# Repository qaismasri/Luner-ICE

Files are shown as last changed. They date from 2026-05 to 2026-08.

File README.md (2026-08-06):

<div align="center">

# Lunar-ICE Rover

**A remotely operated lunar rover that drives a simulated lunar surface and identifies rocks
by their radio, infrared, ultrasonic and magnetic signatures.**

Imperial College London · ELEC40006 Electronics Design Project 1 (EEERover) · Group 15

Documentation
Contents
Sensors
Architecture
Team

</div>

## About the project

The goal was to design and build, from scratch, a remotely controlled rover capable of exploring a simulated lunar surface and surveying the rocks it finds there. The rover has to be driven around large obstacles by a remote operator, park itself next to a target rock, and work out two things about it: **how old it is**, and **what type of rock it is**.

Nothing about the rock is visible from the outside. Everything the rover reports has to be recovered from four faint signals the rock emits — a radio transmission carrying its age, infrared pulses, an ultrasonic tone, and a magnetic field. Each of those needed its own sensor, its own analogue signal chain to pull a usable signal out of the noise, and its own place on the chassis.

The project ran over one term as a six-person group design exercise, and had to satisfy a handful of hard constraints:

- **Under 750 g** all-up mass
- **£60 budget** for components
- **3.3 V logic throughout** — the microcontroller's inputs are not 5 V tolerant
- Driven entirely by a **remote operator**, with no line-of-sight assumptions beyond the same Wi-Fi network

<div align="center">
<table>
<tr>
<td width="50%" align="center" valign="top">
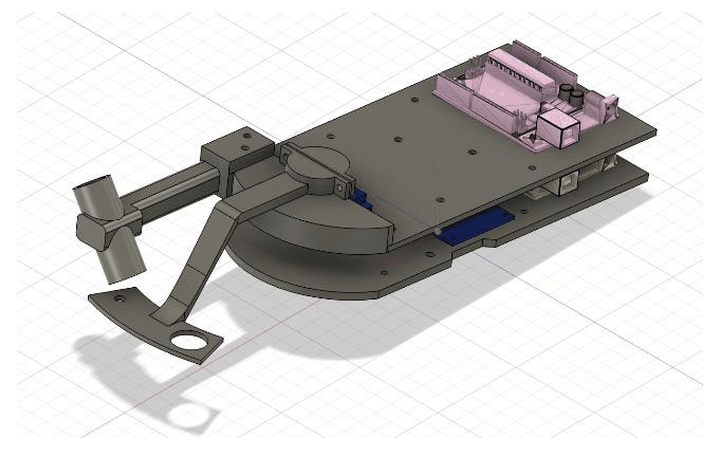
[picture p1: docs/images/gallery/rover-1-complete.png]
Complete rover chassis with both arms

<br><sub><b>Complete assembly</b> — both plates, radio arm and sensor arm</sub>
</td>
<td width="50%" align="center" valign="top">
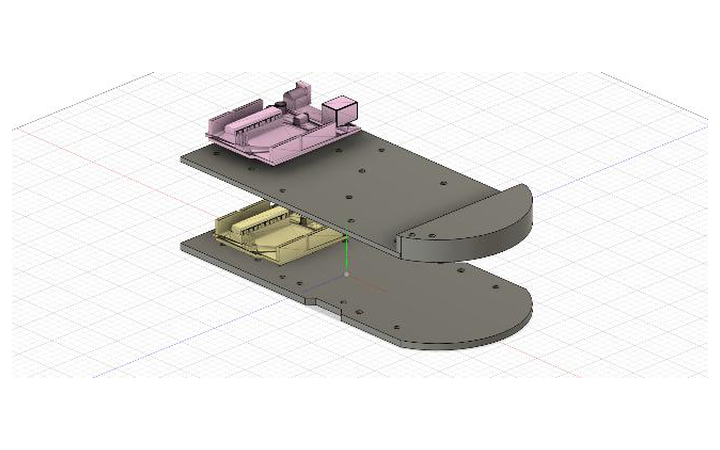
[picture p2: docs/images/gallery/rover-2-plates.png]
Base plate and sensor plate separated

<br><sub><b>Two-plate stack</b> — motors and power below, sensors above</sub>
</td>
</tr>
<tr>
<td width="50%" align="center" valign="top">
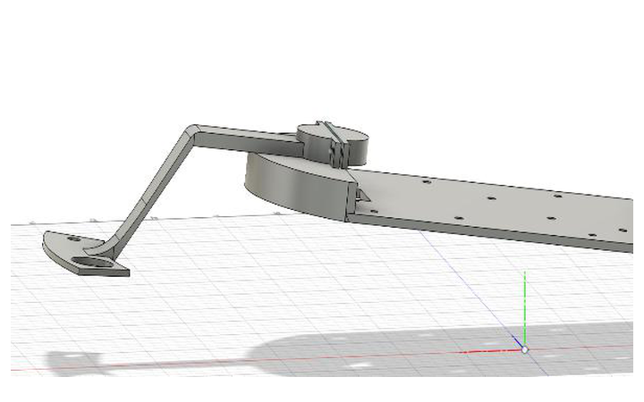
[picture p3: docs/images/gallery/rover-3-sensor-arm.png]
Sensor arm mounted on the chassis

<br><sub><b>Sensor arm</b> — sweeps three sensors across the rock</sub>
</td>
<td width="50%" align="center" valign="top">
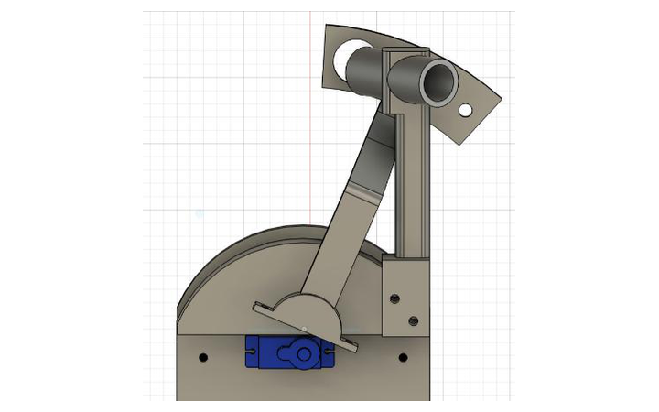
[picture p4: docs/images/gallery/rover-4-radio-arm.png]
Radio antenna arm mounted on the sensor plate

<br><sub><b>Radio arm</b> — fixed, angled down toward the rock</sub>
</td>
</tr>
</table>
</div>

> These are the Fusion 360 renders. Photographs of the built rover are the one thing this repository still lacks — see [the wanted list](docs/images/README.md#photographs-still-wanted).

<div align="right"><a href="#lunar-ice-rover">Back to top</a></div>

## Contents

| Section | What you will find |
|:---|:---|
| **[About the project](#about-the-project)** | Goals, constraints and what the rover has to do |
| **[Team](#team)** | Who built it, and who did what |
| **[The sensors](#the-sensors)** | The four sensing subsystems, one picture each |
| **[Identifying a rock](#identifying-a-rock)** | How four signals become a rock type and an age |
| **[System architecture](#system-architecture)** | The two-board split and how data flows |
| **[Documentation](#documentation)** | All twelve technical chapters |
| **[Repository layout](#repository-layout)** | Where everything lives |
| **[Build and run](#build-and-run)** | Getting it onto the hardware |

For the full technical write-up — calculations, simulations, measurements and PCB files — go to **[the documentation](docs/README.md)**.

<div align="right"><a href="#lunar-ice-rover">Back to top</a></div>

## Team

**Group 15** — six first-year students, with the work split by subsystem.

| Name | Main contributions |
|:---|:---|
| **Tibor Varga** | Radio circuit design and LTspice simulation |
| **Junhao Liu** | Chassis and sensor arm CAD, magnetic sensing |
| **Qais Masri** | Radio research, PCB design, movement and controller, finances |
| **Tunir Sarkar** | Infrared sensor and firmware |
| **Yangping Li** | Motor subsystem and drive integration |
| **Shivang Mehra** | Ultrasound and magnetic sensing, integration |

<div align="right"><a href="#lunar-ice-rover">Back to top</a></div>

## The sensors

Four independent subsystems. The **radio** reports the rock's age; the other three combine to give its type.

<table>
<tr>
<td width="50%" align="center" valign="top">
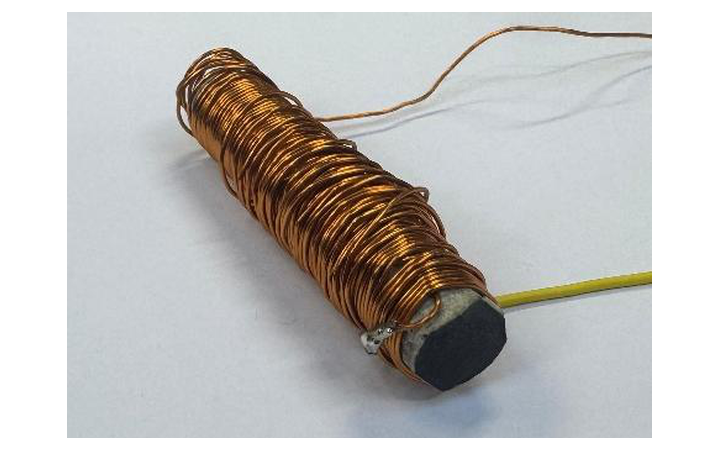
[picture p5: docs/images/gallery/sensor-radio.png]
Hand-wound ferrite coil antenna

<br><b>Radio</b> · rock age
<br><sub>120-turn ferrite coil tuned to 89&nbsp;kHz.<br>ASK carrier, UART at 600&nbsp;baud.</sub>
</td>
<td width="50%" align="center" valign="top">
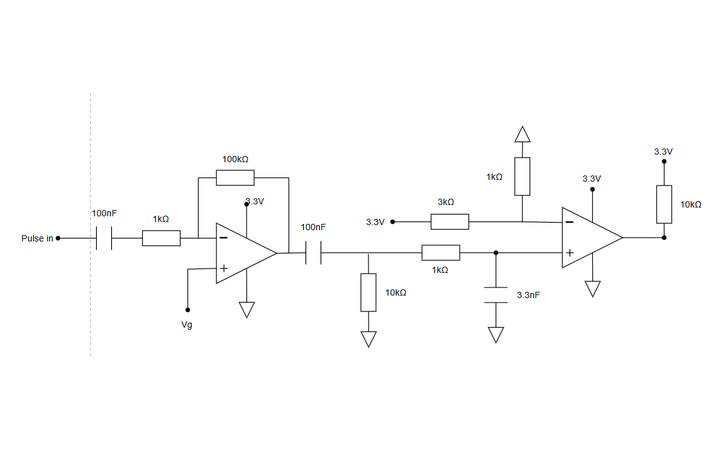
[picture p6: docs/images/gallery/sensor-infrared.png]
Infrared detection circuit

<br><b>Infrared</b> · rock type
<br><sub>SFH300 phototransistor, ×100 amplifier,<br>band-pass filter, LM393 comparator.</sub>
</td>
</tr>
<tr>
<td width="50%" align="center" valign="top">
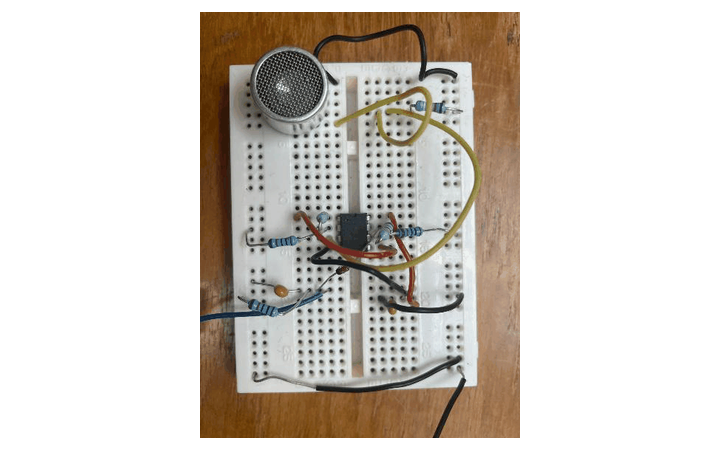
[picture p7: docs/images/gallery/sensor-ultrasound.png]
Ultrasonic receiver circuit on breadboard

<br><b>Ultrasound</b> · rock type
<br><sub>Prowave 400SR160 receiver, two ×34 stages,<br>deliberately clipped, envelope detected.</sub>
</td>
<td width="50%" align="center" valign="top">
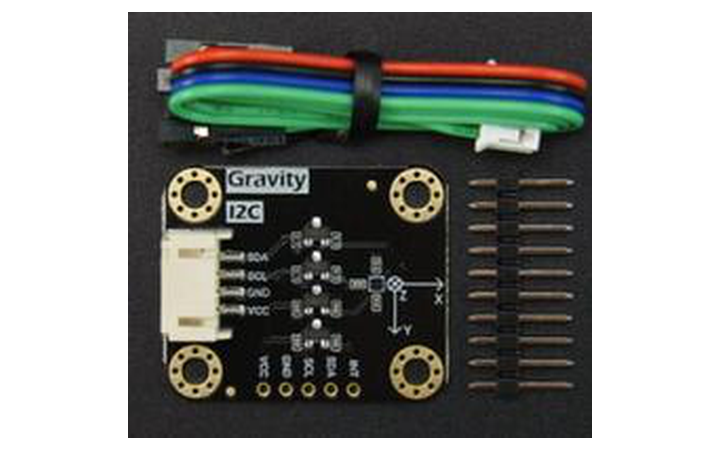
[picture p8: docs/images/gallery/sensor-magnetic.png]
DFRobot SEN0619 magnetometer module

<br><b>Magnetic</b> · rock type
<br><sub>SEN0619 (BMM350) TMR magnetometer,<br>0.1&nbsp;µT resolution over I²C.</sub>
</td>
</tr>
</table>

Click any sensor to read its full design write-up.

<div align="right"><a href="#lunar-ice-rover">Back to top</a></div>

## Identifying a rock

Each rock type maps to a unique combination of the three type-sensors:

| Rock type | Infrared | Ultrasound | Magnetic |
|:---|:---|:---|:---|
| **Basaltoid** | 547 Hz | Present | Down |
| **Gravion** | 312 Hz | Absent | Down |
| **Regolix** | 312 Hz | Present | Up |
| **Lunarite** | 547 Hz | Absent | Up |

Read as a truth table, any **two** of the three columns identify all four types. All three are measured anyway, so they cross-check one another and produce a **confidence score** — the figure that tells the operator when a reading is unreliable and should be rescanned.

The rover is driven and scanned entirely from a browser on the same Wi-Fi network, so the operator needs no special software.

<div align="center">
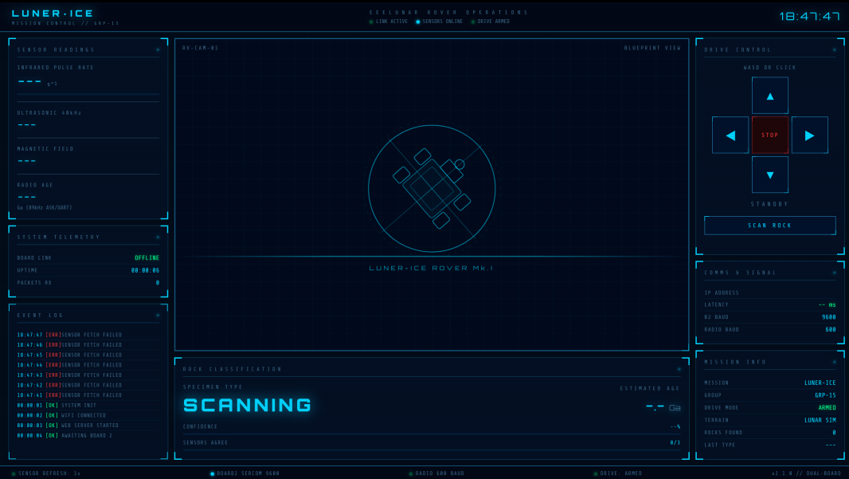
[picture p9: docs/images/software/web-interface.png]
Mission control web interface

</div>

<div align="right"><a href="#lunar-ice-rover">Back to top</a></div>

## System architecture

The rover runs on **two Adafruit Metro M0 Express boards**, split by responsibility. Board 2 does nothing but read sensors; Board 1 handles Wi-Fi, the motors and the classification. Keeping them separate means network activity can never disturb sensor timing.

```mermaid
flowchart LR
    subgraph Rock
        R["Target rock"]
    end

    subgraph B2["Board 2 — Sensing"]
        RAD["Radio<br/>89 kHz ASK"]
        IR["Infrared<br/>pulse counter"]
        US["Ultrasound<br/>40 kHz"]
        MAG["Magnetometer<br/>BMM350"]
    end

    subgraph B1["Board 1 — Control"]
        WEB["Wi-Fi web server"]
        CLS["Classification"]
        MOT["Motor driver"]
    end

    OP(["Operator<br/>browser + gamepad"])

    R --> RAD & IR & US & MAG
    RAD & IR & US & MAG --> PKT["Sensor packet @ 1 Hz"]
    PKT -->|"UART link"| B1
    WEB <-->|HTTP over Wi-Fi| OP
    CLS --> WEB
    MOT --> WHEELS["Drive motors"]
```

<div align="center">
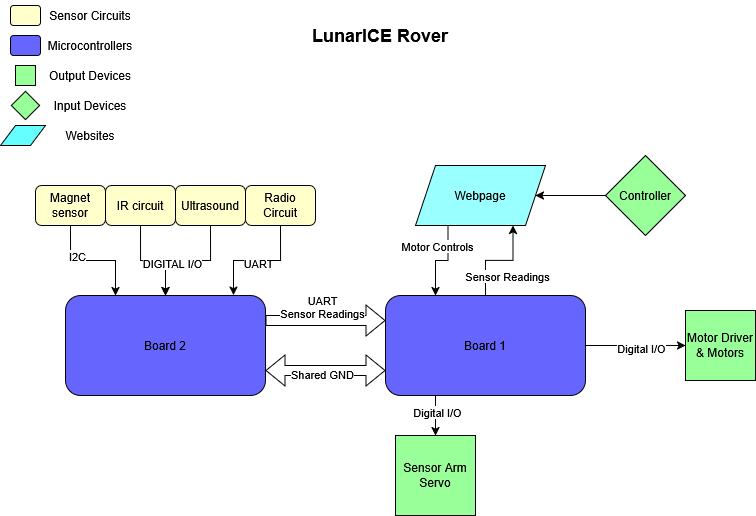
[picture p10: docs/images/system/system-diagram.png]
System diagram of the rover

</div>

<div align="right"><a href="#lunar-ice-rover">Back to top</a></div>

## Documentation

The complete write-up — design reasoning, calculations, LTspice simulations, oscilloscope captures, CAD renders and PCB layouts — lives in [`docs/`](docs/README.md).

| # | Chapter | What it covers |
|:--|:---|:---|
| 01 | [System overview](docs/01-system-overview.md) | Mission objectives, rock types, architecture, data flow |
| 02 | [Infrared sensing](docs/02-infrared.md) | Phototransistor front-end, band-pass filtering, comparator, pulse counting |
| 03 | [Radio sensing](docs/03-radio.md) | Ferrite antenna, tuned LC, amplifier, envelope detector, Schmitt trigger, UART decode |
| 04 | [Ultrasound sensing](docs/04-ultrasound.md) | 40 kHz transducer, two-stage gain, deliberate clipping, envelope detection |
| 05 | [Magnetic field sensing](docs/05-magnetic-field.md) | Hall-effect dead end, switch to a TMR magnetometer, thresholds |
| 06 | [Mechanical design](docs/06-mechanical-design.md) | Two-plate chassis, radio arm, servo-driven sensor sweep arm |
| 07 | [Movement and control](docs/07-movement-and-control.md) | Tank steering, keyboard control, gamepad mixing, latency fix |
| 08 | [PCB design](docs/08-pcb-design.md) | Two-board split, schematics, footprints, layout rules |
| 09 | [Web interface](docs/09-web-interface.md) | Mission control page, chunked serving, scan workflow |
| 10 | [Dual-board architecture](docs/10-dual-board-architecture.md) | Why two boards, the UART link, packet format, classification |
| 11 | [Cost and bill of materials](docs/11-cost-and-bom.md) | Component spend against budget |
| 12 | [References](docs/12-references.md) | Datasheets and sources |

New to the project? Start with [chapter 01](docs/01-system-overview.md).

<div align="right"><a href="#lunar-ice-rover">Back to top</a></div>

## Repository layout

```
Lunar-ICE/
├── docs/                      Technical documentation and all 71 figures
│
├── Full_Board_Code/           Flight firmware — the code that runs on the rover
│   ├── Board 1/               Wi-Fi, web server, motors, rock classification
│   └── Board 2/               All four sensors, streams readings to Board 1
│
├── Lonely_Board/              Single-board prototype (everything on one Metro M0)
│
├── sensing/                   Per-subsystem research, test firmware and PCBs
│   ├── Infrared/              IR pulse-detection test code
│   ├── radio/                 Coil calculations and radio test code
│   ├── ultrasonic/            Ultrasonic test code and design notes
│   ├── magnetic/              Magnetometer test code
│   └── PCBs/                  KiCad projects and manufacturing Gerbers
│
└── software/                  Web interface, servo tests, classification notes
    ├── Website/rover_website/ Board 1 firmware serving mission control
    └── Servo_test/            Sensor-arm servo sweep test
```

Every folder has its own README: [docs](docs/README.md) · [figures](docs/images/README.md) · [firmware](Full_Board_Code/README.md) · [prototype](Lonely_Board/README.md) · [sensing](sensing/README.md) · [software](software/README.md)

<div align="right"><a href="#lunar-ice-rover">Back to top</a></div>

## Build and run

You will need [PlatformIO](https://platformio.org/install) and two Adafruit Metro M0 Express boards, one with a WINC1500 Wi-Fi shield.

```bash
cd "Full_Board_Code/Board 1"     # Wi-Fi, web interface, motors, classification
pio run --target upload

cd "Full_Board_Code/Board 2"     # sensors
pio run --target upload
```

Board 1 prints its IP address over USB serial on boot — open it in a browser on the same network to drive the rover and trigger scans.

Wiring, Wi-Fi credentials and build notes are in **[Full_Board_Code/README.md](Full_Board_Code/README.md)**.

<div align="right"><a href="#lunar-ice-rover">Back to top</a></div>

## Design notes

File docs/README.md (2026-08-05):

[← Repo home](../README.md)

# Lunar-ICE — Technical Documentation

Complete design documentation for the Group 15 Lunar-ICE rover, covering every subsystem from first principles through simulation, bench measurement and final integration.

---

## Chapters

| # | Document | Covers |
|---|---|---|
| 01 | [System overview](01-system-overview.md) | Mission objectives, rock types, architecture, data flow |
| 02 | [Infrared sensing](02-infrared.md) | Phototransistor front-end, band-pass filtering, comparator, pulse counting |
| 03 | [Radio sensing](03-radio.md) | Ferrite antenna, tuned LC, amplifier, envelope detector, Schmitt trigger, UART decode |
| 04 | [Ultrasound sensing](04-ultrasound.md) | 40 kHz transducer, two-stage gain, deliberate clipping, envelope detection |
| 05 | [Magnetic field sensing](05-magnetic-field.md) | Hall-effect dead end, switch to a TMR magnetometer, thresholds |
| 06 | [Mechanical design](06-mechanical-design.md) | Two-plate chassis, radio arm, servo-driven sensor sweep arm |
| 07 | [Movement and control](07-movement-and-control.md) | Tank steering, keyboard control, gamepad mixing, latency fix |
| 08 | [PCB design](08-pcb-design.md) | Two-board split, schematics, footprints, layout rules |
| 09 | [Web interface](09-web-interface.md) | Mission control page, chunked serving, scan workflow |
| 10 | [Dual-board architecture](10-dual-board-architecture.md) | Why two boards, SERCOM UART link, packet format, classification |
| 11 | [Cost and bill of materials](11-cost-and-bom.md) | Component spend against budget |
| 12 | [References](12-references.md) | Datasheets and sources |

Every chapter carries previous / next / index links at the top and bottom, so you can read straight through or jump around.

---

## Reading order

If you are new to the project, read **[01 — System overview](01-system-overview.md)** first. It sets out the mission, the four rock types and how the sensor readings combine into a classification; everything else assumes that context.

The four sensing chapters (**02–05**) are independent of one another and can be read in any order. Chapters **06–10** cover integration and are best read after at least one sensing chapter.

---

## Looking for something specific?

| If you want to… | Go to |
|---|---|
| Understand the whole system in five minutes | [01 — System overview](01-system-overview.md) |
| See how a rock gets classified | [10 § Rock classification](10-dual-board-architecture.md#107-rock-classification) |
| Know why there are two microcontrollers | [10 § Why two boards](10-dual-board-architecture.md#102-why-two-boards) |
| Build or flash the firmware | [Full_Board_Code/README.md](../Full_Board_Code/README.md) |
| Reproduce a sensor circuit | [02](02-infrared.md) · [03](03-radio.md) · [04](04-ultrasound.md) · [05](05-magnetic-field.md) |
| Rebuild the radio front-end step by step | [sensing/radio/README.md](../sensing/radio/README.md) |
| Get the PCB manufacturing files | [08 § Manufacturing files](08-pcb-design.md#87-manufacturing-files) |
| Print the chassis | [06 — Mechanical design](06-mechanical-design.md) |
| See what the interface looks like | [09 — Web interface](09-web-interface.md) |
| Check what was spent | [11 — Cost and BOM](11-cost-and-bom.md) |
| Find a specific figure | [images/README.md](images/README.md) |
| Contribute photographs | [images/README.md § Photographs still wanted](images/README.md#photographs-still-wanted) |

---

## Code and hardware

The documentation explains the design; these folders hold the working files.

| Folder | Contents |
|---|---|
| [`Full_Board_Code/`](../Full_Board_Code/README.md) | Flight firmware for both boards |
| [`Lonely_Board/`](../Lonely_Board/README.md) | Single-board prototype |
| [`sensing/`](../sensing/README.md) | Per-subsystem test firmware, research notes, PCB projects |
| [`software/`](../software/README.md) | Web interface, gamepad driver, servo test |

---

## Figures

All 71 figures live under [`images/`](images/), grouped by subsystem. See **[images/README.md](images/README.md)** for the figure index — and for the list of photographs that would still improve this documentation, chiefly of the assembled rover.

---

## Source

This documentation is derived from the group's submitted project report, *ELEC40006 Project Report — Group 15*, expanded with repository-specific detail (build instructions, file locations, wiring) that the report did not need to carry.

Where the report and this documentation disagree on a number, the discrepancy is called out explicitly in place — see [11 § A note on the conflicting totals](11-cost-and-bom.md#112-a-note-on-the-conflicting-totals) for the one instance.

---

[← Repo home](../README.md)

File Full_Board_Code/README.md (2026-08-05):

[← Repo home](../README.md) · [Technical documentation](../docs/README.md)

# Flight Firmware — Dual-Board Setup

The code that actually runs on the Lunar-ICE rover. Two independent [PlatformIO](https://platformio.org/) projects, one per Adafruit Metro M0 Express board.

> **Full write-up:** [docs/10-dual-board-architecture.md](../docs/10-dual-board-architecture.md)

---

## The two boards

| | [`Board 1/`](Board%201/) | [`Board 2/`](Board%202/) |
|---|---|---|
| **Role** | Control | Sensing |
| **Responsibilities** | Wi-Fi, web interface, motors, rock classification | Radio, infrared, ultrasonic, magnetic |
| **Shield** | WINC1500 Wi-Fi | — |
| **Link** | Receives on pin 11 | Sends on pin 10 |
| **Env name** | `board1_main` | `board2_sensors` |

Board 2 sends one newline-terminated CSV packet per second:

```
AGE:3.82,IR:539,IRC:547,IRCO:93,US:1,MAG:DOWN
```

---

## Wiring between the boards

Two conductors — the link is one-way, because Board 2 only ever sends.

```
Board 2 pin 10 (TX)  ──────▶  Board 1 pin 11 (RX)
Board 2 GND          ───────  Board 1 GND
```

The link runs on **SERCOM1** at 9600 baud, mapped to those pins with `pinPeripheral()`. Pin 0 was unavailable on both boards — taken by the radio on Board 2, and physically dead on Board 1.

---

## Building and uploading

```bash
# Board 1
cd "Board 1"
pio run --target upload

# Board 2
cd "Board 2"
pio run --target upload
```

**Before flashing Board 1**, set your Wi-Fi credentials near the top of `Board 1/src/main.cpp`. On boot Board 1 prints its IP address over USB serial:

```bash
pio device monitor
```

Open that address in a browser on the same network to reach mission control.

---

## Build notes

**`lib_ignore = Adafruit TinyUSB Library` is required** in both `platformio.ini` files. Without it the build fails on a USB symbol conflict with the WiFi101 stack. Do not remove it.

**Board 1 resource use:** ~38% of 256 KB flash, ~18% of 32 KB RAM. The web page is stored as a string in flash and streamed to the browser in 500-byte chunks — sending it in one transfer crashes the WINC1500 driver.

---

## Related

| | |
|---|---|
| Single-board prototype | [`Lonely_Board/`](../Lonely_Board/) |
| Per-sensor test firmware | [`sensing/`](../sensing/) |
| Web interface source | [`software/Website/rover_website/`](../software/Website/rover_website/) |

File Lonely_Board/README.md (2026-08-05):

[← Repo home](../README.md) · [Technical documentation](../docs/README.md)

# Single-Board Prototype

A complete, working implementation of the entire rover on **one** Adafruit Metro M0 Express — sensors, Wi-Fi, web interface, motors and classification in a single sketch.

> This is **not** the firmware that runs on the finished rover. That is in [`Full_Board_Code/`](../Full_Board_Code/).

---

## Why it exists

The final rover uses two boards. That was a deliberate design choice rather than a necessity, and this project is the evidence: a single Metro M0 genuinely can run the whole system. The 48 MHz Cortex-M0+ has ample compute, the time-sensitive inputs are protected by hardware (infrared on an interrupt, radio in an interrupt-driven UART buffer, motors on hardware PWM), and the firmware fits comfortably.

The split to two boards was made for **timing isolation** — serving the web page over the WINC1500 blocks the processor in bursts, which would otherwise disturb the 50 µs infrared pulse measurements — plus parallel development and a cleaner separation of concerns.

The full argument is in [docs/10-dual-board-architecture.md § 10.2](../docs/10-dual-board-architecture.md#102-why-two-boards).

---

## Keeping it around

It stays in the repository for three reasons:

1. It documents the alternative that was considered and measured, rather than merely asserted.
2. It is a useful fallback if one board fails during a demonstration.
3. It is the simplest place to reproduce an end-to-end bug without the inter-board link in the way.

---

## Building

```bash
pio run --target upload
```

Set your Wi-Fi credentials near the top of `src/main.cpp` first. On boot the board prints its IP address over USB serial.

Uses the [DFRobot_BMM350](https://github.com/DFRobot/DFRobot_BMM350) library for the magnetometer, pulled automatically via `lib_deps`.

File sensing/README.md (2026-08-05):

[← Repo home](../README.md) · [Technical documentation](../docs/README.md)

# Sensing

Research, circuit design, test firmware and PCB files for all four sensing subsystems on the Lunar-ICE rover.

Each subsystem detects one property of a rock and reduces it to a signal the Metro M0 can read. The full write-up for each — design reasoning, calculations, simulations and measurements — is in [`docs/`](../docs/); this folder holds the working files.

---

## Subsystems

| Subsystem | Detects | Documentation | Test firmware | Status |
|---|---|---|---|---|
| **Radio** | Rock age, via 89 kHz ASK | [docs/03-radio.md](../docs/03-radio.md) | [`radio/radio_test_code/`](radio/radio_test_code/) | ✅ Working |
| **Infrared** | Rock type, via pulse rate | [docs/02-infrared.md](../docs/02-infrared.md) | [`Infrared/ir_test_code/`](Infrared/ir_test_code/) | ✅ Working |
| **Ultrasound** | Rock type, via 40 kHz tone | [docs/04-ultrasound.md](../docs/04-ultrasound.md) | [`ultrasonic/ultrasonic_test_code/`](ultrasonic/ultrasonic_test_code/) | ✅ Working |
| **Magnetic** | Rock type, via magnet polarity | [docs/05-magnetic-field.md](../docs/05-magnetic-field.md) | [`magnetic/Magnetic_test_code/`](magnetic/Magnetic_test_code/) | ✅ Working |

---

## Folder contents

```
sensing/
├── Infrared/
│   └── ir_test_code/                  Pulse counting via hardware interrupt
├── radio/
│   ├── COIL_CALCULATIONS.md           Ferrite coil inductance and resistance working
│   ├── step1_coil_antenna.png         The wound coil
│   └── radio_test_code/               UART decode of the demodulated bitstream
├── ultrasonic/
│   ├── Ultrasonic_sensor_notes.md     Transducer, gain planning and test log
│   └── ultrasonic_test_code/          Digital-level presence detection
├── magnetic/
│   └── Magnetic_test_code/            BMM350 read over I²C
├── radio_ultrasound_magnetic/         Combined three-sensor integration test
└── PCBs/                              KiCad projects and manufacturing Gerbers
```

Each folder containing a `platformio.ini` is a standalone [PlatformIO](https://platformio.org/) project:

```bash
cd sensing/Infrared/ir_test_code
pio run --target upload
```

The **flight firmware** that actually runs on the rover is not here — it is in [`Full_Board_Code/Board 2/`](../Full_Board_Code/Board%202/), which combines all four subsystems. The projects in this folder are the per-subsystem test rigs used during development, kept because they are the quickest way to bring one sensor up in isolation when debugging.

---

## How it fits together

```mermaid
flowchart LR
    A["🪨 Rock"] --> B["Radio<br/>89 kHz ASK"]
    A --> C["Infrared<br/>312 / 547 Hz"]
    A --> D["Ultrasound<br/>40 kHz"]
    A --> E["Magnetic<br/>up / down"]

    B --> F["Board 2<br/>Metro M0"]
    C --> F
    D --> F
    E --> F

    F -->|"CSV packet @ 1 Hz over UART"| G["Board 1"]
    G --> H["Rock classification"]
```

The radio yields the rock's **age**. The other three combine to give its **type** — see [Rock classification](../docs/10-dual-board-architecture.md#107-rock-classification).

---

## PCBs

Two boards were manufactured. See [docs/08-pcb-design.md](../docs/08-pcb-design.md) for schematics, layout rules and 3D renders.

| Board | KiCad project | Gerbers |
|---|---|---|
| Radio | [`PCBs/Radio PCB/`](PCBs/Radio%20PCB/) | [`PCBs/Radio final PCB/`](PCBs/Radio%20final%20PCB/) |
| IR + ultrasound | [`PCBs/IR + ultrasound/`](PCBs/IR%20+%20ultrasound/) | [`PCBs/Infrared final pcb/`](PCBs/Infrared%20final%20pcb/) |
| Demo | [`PCBs/Demo pcb/`](PCBs/Demo%20pcb/) | [`PCBs/Final files greber/`](PCBs/Final%20files%20greber/) |

Magnetic sensing needs no PCB — the SEN0619 module outputs digitally over I²C and wires straight to the Metro.

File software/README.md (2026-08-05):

[← Repo home](../README.md) · [Technical documentation](../docs/README.md)

# Software

The operator-facing side of the Lunar-ICE rover: the mission control web interface, the classification logic, and the servo test rig.

---

## Contents

| Item | What it is |
|---|---|
| [`Website/rover_website/`](Website/rover_website/) | Board 1 firmware serving the mission control page, plus the gamepad driver |
| [`eeerover_mission_control_demo.html`](eeerover_mission_control_demo.html) | Standalone copy of the page — open it in a browser to preview the UI without hardware |
| [`Servo_test/`](Servo_test/) | Sensor-arm servo sweep test |
| [`rock_classification.md`](rock_classification.md) | Reference implementation of the four-way rock lookup |
| [`arduino_capabilities.md`](arduino_capabilities.md) | Early one-board-versus-two design note, kept for the record |

---

## Mission control

The rover is driven and monitored entirely through a browser on the same Wi-Fi network. Board 1 serves the page and prints its IP address over USB serial on boot.

| Topic | Documentation |
|---|---|
| What the page shows, chunked serving, scan workflow | [docs/09-web-interface.md](../docs/09-web-interface.md) |
| Tank steering, gamepad mixing, the latency fix | [docs/07-movement-and-control.md](../docs/07-movement-and-control.md) |
| Classification and confidence scoring | [docs/10-dual-board-architecture.md § 10.7](../docs/10-dual-board-architecture.md#107-rock-classification) |

### Previewing the interface without hardware

```bash
# macOS / Linux
open software/eeerover_mission_control_demo.html

# Windows
start software\eeerover_mission_control_demo.html
```

Drive controls and live readings will not do anything without a rover to talk to, but the layout, styling and animations all render.

---

## Gamepad support

[`Website/rover_website/src/gamepad.js`](Website/rover_website/src/gamepad.js) uses the browser's built-in Gamepad API for analogue steering:

| Input | Index | Meaning |
|---|---|---|
| Right trigger | `buttons[7]` | Forward throttle |
| Left trigger | `buttons[6]` | Reverse throttle |
| Right stick X | `axes[2]` | Steering |

Throttle and steer are mixed into per-wheel speeds and sent as `GET /drive?left=L&right=R`. A ±0.15 dead zone suppresses stick drift, and requests are sent only when values change — the original implementation fired ~30 requests per second and built up a command backlog that made the rover keep turning after the stick was released. See [docs/07-movement-and-control.md § 7.5](../docs/07-movement-and-control.md#75-the-latency-problem-and-the-fix).

---

## Building

Both PlatformIO projects build and upload the same way:

```bash
cd software/Website/rover_website
pio run --target upload
```

Set your Wi-Fi credentials near the top of `src/main.cpp` before flashing.

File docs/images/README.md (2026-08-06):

[← Documentation index](../README.md) · [Repo home](../../README.md)

# Figure Index

All figures used in the [technical documentation](../README.md), grouped by subsystem. **71 figures**, extracted from the group's project report and re-encoded for the web (longest edge capped at 1400 px).

Naming convention: `<subsystem>-<what-it-shows>.png`. Simulation captures carry `ltspice`, oscilloscope captures carry `scope`.

---

## Contents

- [Existing figures](#existing-figures)
- [Photographs still wanted](#photographs-still-wanted) ← **contributions go here**

---

## Existing figures

### `system/` — 1 figure

| File | Shows |
|---|---|
| `system-diagram.png` | Block diagram of the whole rover: sensors, both boards, motors, webpage, controller |

### `infrared/` — 13 figures

| File | Shows |
|---|---|
| `ir-virtual-ground.png` | Virtual ground potential divider, ~1.5 V at `Vg` |
| `ir-phototransistor-model.png` | Current source + NPN model of the SFH300 |
| `ir-inverting-amplifier.png` | Inverting amplifier, gain 100 |
| `ir-high-pass-filter.png` | 159 Hz high-pass stage |
| `ir-high-pass-bode.png` | High-pass magnitude response |
| `ir-low-pass-filter.png` | 48 kHz low-pass stage |
| `ir-band-pass-bode.png` | Combined 159 Hz – 48 kHz response |
| `ir-scope-amplified-pulses.png` | Amplified pulses, Vpp 900 mV |
| `ir-scope-comparator-out.png` | LM393 digital output |
| `ir-scope-pulse-zoom.png` | Single pulse showing noisy edges |
| `ir-scope-noisy-edge.png` | Residual noise before the threshold was raised |
| `ir-scope-smoothed-edge.png` | Clean edge after low-pass + higher threshold |
| `ir-full-circuit.png` | Complete IR signal chain schematic |

### `radio/` — 25 figures

| File | Shows |
|---|---|
| `radio-ask-uart-frame.png` | ASK on-off keying and UART frame structure |
| `radio-ferrite-coil.png` | Hand-wound 120-turn ferrite coil antenna |
| `radio-tuned-lc-circuit.png` | Tuned LC, 517 µH with 6.6 nF |
| `radio-ltspice-sources.png` | LTspice carrier and modulation source definitions |
| `radio-ltspice-ask-signal.png` | Simulated ASK waveform |
| `radio-scope-raw-ask.png` | Measured ASK signal at the antenna |
| `radio-mcp6002-slew-vs-temp.png` | MCP6002 slew rate vs temperature (rejected part) |
| `radio-mcp6022-slew-vs-temp.png` | MCP6022 slew rate vs temperature (selected part) |
| `radio-amplifier-schematic.png` | Non-inverting amplifier, gain 101 |
| `radio-ltspice-amplified.png` | Simulated rail-clipped amplifier output |
| `radio-scope-amplified.png` | Measured amplified signal |
| `radio-scope-raw-vs-amplified.png` | Raw against amplified, showing negative-half clipping |
| `radio-envelope-schematic.png` | Diode + 10 nF + 10 kΩ envelope detector |
| `radio-ltspice-envelope.png` | Simulated envelope output |
| `radio-ltspice-envelope-vs-amp.png` | Envelope overlaid on the amplified signal |
| `radio-ltspice-envelope-ripple.png` | Zoomed ripple from per-cycle discharge |
| `radio-ltspice-envelope-rc-too-big.png` | R = 30 kΩ — capacitor fails to fully discharge |
| `radio-scope-envelope.png` | Measured envelope output |
| `radio-scope-envelope-vs-amp.png` | Measured 0.64 V diode drop between stages |
| `radio-comparator-schematic.png` | Non-inverting comparator with divider-set threshold |
| `radio-ltspice-comparator.png` | Simulated clean 0–3 V digital output |
| `radio-ltspice-envelope-vs-digital.png` | Envelope and digital output overlaid at the 1.6 V crossing |
| `radio-scope-digital-out.png` | Measured digital output, 3.44 V |
| `radio-scope-amplified-vs-digital.png` | ASK input against recovered binary output |
| `radio-breadboard-final.png` | Complete radio front-end on breadboard |

### `ultrasound/` — 8 figures

| File | Shows |
|---|---|
| `us-sensitivity-vs-load.png` | 400SR160 sensitivity vs load resistance |
| `us-lt1366-gain-phase.png` | LT1366 gain and phase vs frequency (rejected part) |
| `us-mcp6022-open-loop-gain.png` | MCP6022 open-loop gain and phase (selected part) |
| `us-ltspice-circuit.png` | Full simulated circuit — two gain stages + envelope detector |
| `us-ltspice-envelope-output.png` | Simulated output settling to ~2.3 V |
| `us-breadboard-final.png` | Final circuit on breadboard with transducer |
| `us-scope-signal-present.png` | Output with 40 kHz present, ~2.63 V |
| `us-scope-signal-absent.png` | Output with no signal, ~45.6 mV |

### `magnetic/` — 3 figures

| File | Shows |
|---|---|
| `mag-ah49e-hall-sensor.png` | AH49E linear Hall-effect sensor (first attempt) |
| `mag-sen0619-module.png` | DFRobot SEN0619 / BMM350 magnetometer module |
| `mag-z-reading-vs-distance.png` | Z-axis reading vs distance, with the ±170 µT thresholds marked |

### `mechanical/` — 10 figures

| File | Shows |
|---|---|
| `chassis-complete.png` | Complete chassis CAD render with both arms |
| `chassis-plates-exploded.png` | Base plate and sensor plate separated |
| `radio-arm-initial.png` | Initial glued radio antenna holder |
| `radio-arm-initial-too-high.png` | Test fit — antenna sitting too far from the rock |
| `radio-arm-redesigned.png` | Screwed redesign at the correct height |
| `radio-arm-mounted-side.png` | Radio arm mounted on the sensor plate |
| `sensor-arm-sweep-restriction.png` | The 23° rightward sweep restriction |
| `sensor-arm-labelled.png` | Sensor arm with IR, ultrasound and magnetometer positions labelled |
| `sensor-arm-on-chassis.png` | Sensors arranged along the sweep arc |
| `sensor-arm-arc-support.png` | Arced support platform under the arm |

### `pcb/` — 8 figures

| File | Shows |
|---|---|
| `pcb-radio-schematic.png` | Radio board KiCad schematic |
| `pcb-radio-layout.png` | Radio board layout with ground plane |
| `pcb-radio-3d-render.png` | Radio board 3D render |
| `pcb-ir-ultrasound-schematic.png` | IR + ultrasound KiCad schematic |
| `pcb-ir-ultrasound-layout.png` | IR + ultrasound board layout |
| `pcb-ir-ultrasound-3d-render.png` | IR + ultrasound board 3D render |
| `pcb-unused-channels-schematic.png` | Unused MCP6022 and LM393 channels tied off safely |
| `pcb-kicad-footprint-manager.png` | KiCad footprint manager during component selection |

### `software/` — 3 figures

| File | Shows |
|---|---|
| `web-interface.png` | Mission control page in the browser |
| `flowchart-board1.png` | Board 1 firmware flowchart |
| `flowchart-board2.png` | Board 2 firmware flowchart |

---

## Derived assets

These are generated from the figures above rather than taken from the report. They exist to give the root README a consistent look; nothing in the documentation chapters depends on them.

### `gallery/` — 8 images

Each source figure is fitted onto a common 720 × 450 canvas with **transparent** padding, so the cells of the two galleries in the root README line up regardless of the source aspect ratio. Transparency means they adapt to the reader's light or dark theme.

**Rover gallery** — the four views at the top of the README:

| File | Built from |
|---|---|
| `rover-1-complete.png` | `mechanical/chassis-complete.png` |
| `rover-2-plates.png` | `mechanical/chassis-plates-exploded.png` |
| `rover-3-sensor-arm.png` | `mechanical/sensor-arm-on-chassis.png` |
| `rover-4-radio-arm.png` | `mechanical/radio-arm-mounted-side.png` |

**Sensor gallery** — one picture per subsystem:

| File | Built from |
|---|---|
| `sensor-radio.png` | `radio/radio-ferrite-coil.png` |
| `sensor-infrared.png` | `infrared/ir-full-circuit.png` |
| `sensor-ultrasound.png` | `ultrasound/us-breadboard-final.png` |
| `sensor-magnetic.png` | `magnetic/mag-sen0619-module.png` |

**If you replace a source figure**, regenerate the matching gallery image so the two stay in step. Every rover-gallery image is currently a CAD render — swapping in photographs of the built rover is the single biggest improvement available to this repository.

### `nav/` — 6 images

Button images for the root README. GitHub strips CSS from Markdown, so plain links cannot be restyled; rendering navigation as images is the only way to make it read as buttons rather than blue text. They are generated locally rather than pulled from a badge service, so the README has no external dependencies and renders offline.

Section jumps: `btn-documentation.png` (accent) · `btn-contents.png` · `btn-sensors.png` · `btn-architecture.png` · `btn-team.png`

Back to top: `btn-top.png` — the small muted pill repeated at the end of each README section.

---

## Photographs still wanted

Everything above documents the **design**. What the documentation lacks almost entirely is evidence of the **built rover** — there is not a single photograph of the finished machine anywhere in this repository.

That is the largest remaining gap. Anyone assessing this project will want to see that the design became a working object.

The slots below are reserved. Drop a file at the given path and the documentation will pick it up — each one is already referenced from the relevant page, so no editing is needed beyond adding the image.

### Priority 1 — the finished rover

| Path | What to shoot |
|---|---|
| `mechanical/rover-assembled.jpg` | **Most important.** Three-quarter view of the complete rover: both plates, wheels, both arms, wiring. Plain background, even lighting. Destined for the top of the root README. |
| `mechanical/rover-side-profile.jpg` | Side-on, showing the 35 mm plate separation and the sensor arm's ground clearance. |
| `mechanical/rover-scanning-rock.jpg` | Parked at a rock mid-scan with the arm swept over it. Shows the working geometry better than any render. |
| `mechanical/rover-top-down.jpg` | Directly overhead, showing the sensor plate layout — PCBs, Board 2, arm pivot. |
| `infrared/ir-breadboard-final.jpg` | The infrared circuit built on breadboard. **This is the one sensor gallery cell on the front page still showing a schematic rather than real hardware** — radio, ultrasound and magnetic are all photographs. Shoot this and regenerate `gallery/sensor-infrared.png` from it. |

### Priority 2 — subassemblies

| Path | What to shoot |
|---|---|
| `mechanical/sensor-arm-built.jpg` | Printed arm with IR, ultrasonic and magnetometer sensors fitted. |
| `mechanical/chassis-underside.jpg` | Underside of the base plate: motor mounting and notches. |
| `pcb/pcb-radio-populated.jpg` | Manufactured radio board, soldered. |
| `pcb/pcb-ir-ultrasound-populated.jpg` | Manufactured IR + ultrasound board, soldered. |
| `pcb/pcbs-mounted-on-chassis.jpg` | Both boards screwed to the sensor plate and wired in. |
| `radio/radio-antenna-mounted.jpg` | The ferrite coil in its arm on the rover, showing the downward angle. |

### Priority 3 — evidence and context

| Path | What to shoot |
|---|---|
| `software/web-interface-classified.png` | Screenshot immediately after a successful scan, showing a rock type, age and confidence figure. The current screenshot shows the page mid-scan. |
| `software/web-interface-mobile.png` | The page on a phone, demonstrating the responsive layout. |
| `system/rover-in-arena.jpg` | The rover on the test surface among the rocks — gives scale and context. |
| `system/team-photo.jpg` | The group with the finished rover. |
| `mechanical/print-in-progress.jpg` | A plate being 3D printed — supports the material discussion in [06](../06-mechanical-design.md#material-choice). |

### If you shoot new photographs

- **JPEG for photographs, PNG for screenshots and diagrams.** JPEG artefacts ruin text and line art; PNG bloats photographs.
- **Cap the longest edge at 1600 px.** Everything already here is capped at 1400 px, and the whole set totals ~5 MB.
- **Keep the filename exactly as listed above** so the existing references resolve.
- Plain, uncluttered background; diffuse light; avoid direct flash on the PCBs.

---

[← Documentation index](../README.md) · [Repo home](../../README.md)

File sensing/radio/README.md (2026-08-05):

[← sensing/](../README.md) · [Repo home](../../README.md) · [Technical documentation](../../docs/README.md)

# Radio Subsystem — Age Detection

**Signal:** 89 kHz carrier, amplitude-shift keyed, UART encoded at 600 baud
**Output:** rock age as an ASCII string — `#123` means 1.23 billion years

> **Full write-up:** [docs/03-radio.md](../../docs/03-radio.md) — design reasoning, LTspice simulations, oscilloscope captures and measured results for every stage.
> This page is the build guide: what to make, in what order, and what to check before moving on.

---

## Signal processing chain

```mermaid
flowchart TD
    A["🪨 Rock transmits 89 kHz ASK signal"] --> B
    B["1. Coil antenna<br/>Ferrite-cored inductor<br/>Picks up 89 kHz radio waves"] --> C
    C["2. Tuned LC circuit<br/>Antenna coil + capacitor<br/>Resonates at 89 kHz, filters noise"] --> D
    D["3. Amplifier<br/>Op-amp, high slew rate required<br/>Boosts signal to usable voltage"] --> E
    E["4. Envelope detector<br/>Diode + capacitor rectifier<br/>Strips carrier, keeps data shape"] --> F
    F["5. Comparator<br/>Compares against threshold voltage<br/>Outputs clean binary"] --> G
    G["6. Metro M0 UART decode<br/>Pin 0, 600 baud"] --> H
    H(["✅ Age value extracted<br/>#123 → 1.23 billion years"])
```

---

## Build order

Each step should be verified on the oscilloscope before the next is added. Debugging a five-stage analogue chain built all at once is far harder than building it one stage at a time.

### Step 1 — Coil antenna

Wind copper wire around a ferrite core to form an inductor. Ferrite was chosen over a plain air core because it significantly increases inductance for the same number of turns and physical size, improving sensitivity to weak signals. Measure the finished coil's inductance with the lab LCR bridge — **use the measured value, not the calculated one, to size the tuning capacitor.**

| Parameter | Value |
|---|---|
| Core | Ferrite, 1 cm diameter × 5.5 cm |
| Turns | 120 |
| Wire | 0.40 mm enamelled copper |
| Measured inductance | 517 µH |
| Measured resistance | 0.488 Ω |

Full calculations: [COIL_CALCULATIONS.md](COIL_CALCULATIONS.md)

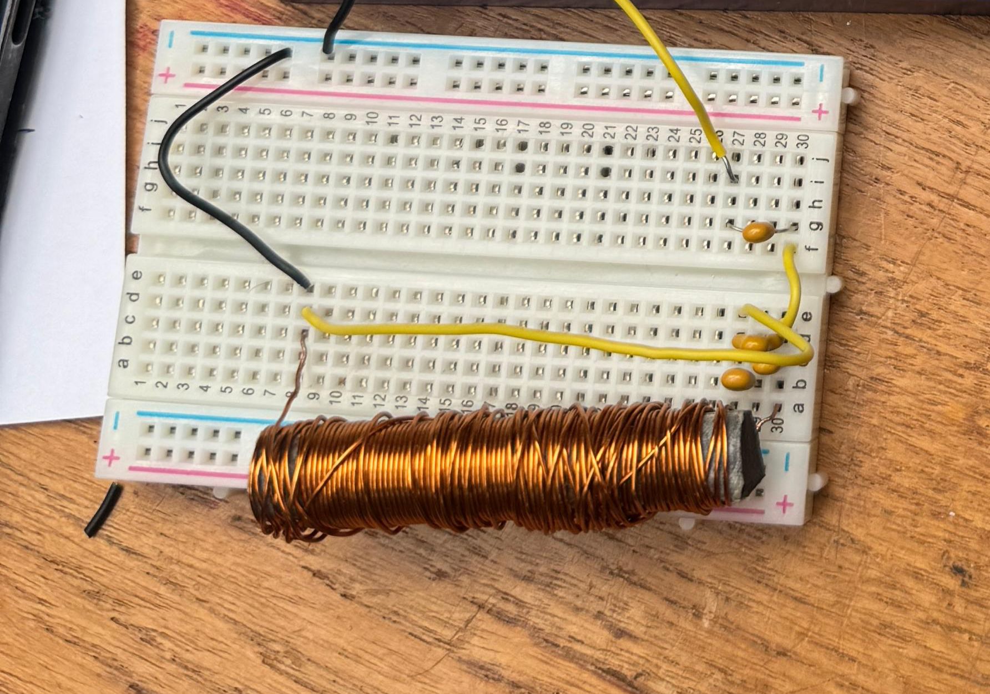
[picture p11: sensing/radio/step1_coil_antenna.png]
Coil antenna


**Check before moving on:** LCR bridge gives a stable inductance reading in the expected range.

---

### Step 2 — Tuned LC circuit

Pair the coil with a capacitor to form a resonant circuit at 89 kHz:

$$f_0 = \frac{1}{2\pi\sqrt{LC}} \implies C = \frac{1}{(2\pi f_0)^2 L}$$

For 517 µH this gives 6.18 nF, built from real capacitors as **6.6 nF**.

**Check before moving on:** the signal at the coil peaks when the rock is near and perpendicular to it. Amplitude varies dramatically with distance and orientation — this is expected.

📷 *A photo of the built LC stage would go well here.*

---

### Step 3 — Amplifier

The antenna output is in the millivolt range. Use a non-inverting op-amp stage with a gain around 100. The op-amp must have enough gain-bandwidth product **and** slew rate at 89 kHz.

**Use the MCP6022**, not the MCP6002. The MCP6002's 1 MHz GBW limits usable gain at 89 kHz to about ×11, and its slew rate is marginal at 3.3 V. The MCP6022 gives 10 MHz GBW and 7 V/µs in the same pinout.

**Check before moving on:** output clips against the rails when the rock is close. Clipping is intended — see [docs/03-radio.md § 3.3](../../docs/03-radio.md#33-amplification).

📷 *A photo of the built amplifier stage would go well here.*

---

### Step 4 — Envelope detector

The Metro cannot sample at 89 kHz, so strip the carrier and keep the on/off envelope. A diode, capacitor and resistor do this.

With R = 10 kΩ and C = 10 nF, τ = 100 µs and $f_c$ = 1.59 kHz — comfortably below 89 kHz and above 600 Hz.

**Check before moving on:** the output follows the data envelope with a visible ~0.6 V diode drop, and the capacitor fully discharges between bits. If it does not, R is too large.

📷 *A photo of the built envelope detector would go well here.*

---

### Step 5 — Comparator

Converts the smoothed analogue signal into clean logic levels. Set the threshold with a potential divider.

The threshold is a genuine trade-off: too low and noise triggers it, too high and the signal fails to cross it at range. **≈0.75 V** was the value settled on, lower than the simulated half-supply figure, to preserve detection range.

**Check before moving on:** clean 0–3.3 V square wave with no ripple on the "on" cycles.

📷 *A photo of the built comparator stage would go well here.*

---

### Step 6 — Metro M0 UART decode

Feed the binary signal into **pin 0**. Configure `Serial1` at 600 baud. Use the USB serial port separately for debugging. Data arrives LSB first.

```cpp
void setup() {
  Serial.begin(9600);   // USB debug port
  Serial1.begin(600);   // Rock signal on Pin 0
}

void loop() {
  if (Serial1.available()) {
    char c = Serial1.read();
    Serial.print(c);    // Print to debug monitor
  }
}
```

> **Add a 1 kΩ series resistor** between the comparator output and the Metro input pin. Without it the Metro's internal protection diodes back-drive the comparator, clamping the signal so it never reaches a full 0–3.3 V swing. This one is easy to lose hours to.

**Check:** the `#` character appears in the serial monitor, followed by three digits.

📷 *A photo of the Metro wiring would go well here.*

---

## Components

| Component | Purpose | Selected |
|---|---|---|
| 0.40 mm enamelled copper wire | Coil antenna | ✅ Lab stock |
| Ferrite core, 1 cm × 5.5 cm | Coil antenna | ✅ Lab stock |
| Capacitors totalling 6.6 nF | LC tuning | ✅ Lab stock |
| MCP6022 | Amplifier | ✅ £1.44 |
| 1N4148 | Envelope detector | ✅ Lab stock |
| LM393 | Comparator | ✅ £0.32 |
| Resistors | Threshold, gain, RC | ✅ Lab stock |

---

## Testing checklist

- [x] Coil built and inductance measured with LCR bridge
- [x] LC circuit resonating at 89 kHz, verified on oscilloscope
- [x] Amplifier output visible and clipping to rails
- [x] Envelope detector showing clean data shape
- [x] Comparator outputting clean logic levels
- [x] Metro receiving and printing `#` via serial monitor
- [x] Full age string decoded correctly from rock simulator

---

## Firmware

| | |
|---|---|
| Test code | [`radio_test_code/`](radio_test_code/) |
| Flight code | [`Full_Board_Code/Board 2/`](../../Full_Board_Code/Board%202/) |

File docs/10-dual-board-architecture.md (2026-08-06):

[← Web interface](09-web-interface.md) · [Documentation index](README.md) · [Repo home](../README.md) · [Next: Cost and bill of materials →](11-cost-and-bom.md)

# 10. Dual-Board Architecture

**Hardware:** two Adafruit Metro M0 Express boards (SAMD21, 48 MHz Cortex-M0+)
**Link:** one-way hardware UART on SERCOM1, 9600 baud
**Firmware:** [`Full_Board_Code/Board 1/`](../Full_Board_Code/Board%201/) and [`Full_Board_Code/Board 2/`](../Full_Board_Code/Board%202/)

---

## 10.1 Overview

| | Board 1 | Board 2 |
|---|---|---|
| **Role** | Control | Sensing |
| **Responsibilities** | Wi-Fi, web interface, motors, rock classification | Radio, infrared, ultrasonic, magnetic |
| **Shield** | WINC1500 Wi-Fi | — |
| **Data flow** | Receives | Sends |

Board 2 streams its readings to Board 1 over a one-way UART link. A single board **could** have run the whole system — using two was a deliberate design choice, and the reasoning is set out below.

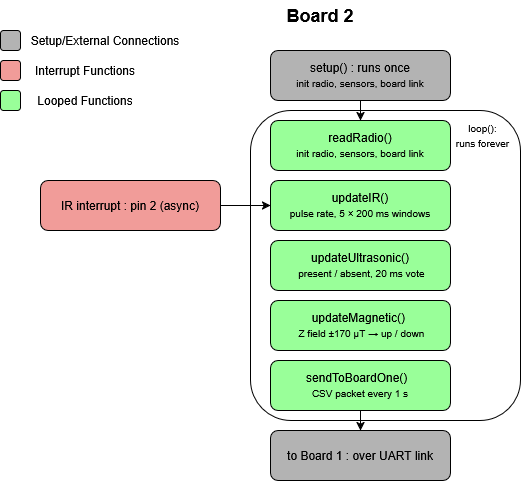
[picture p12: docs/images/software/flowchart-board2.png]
Board 2 software flowchart

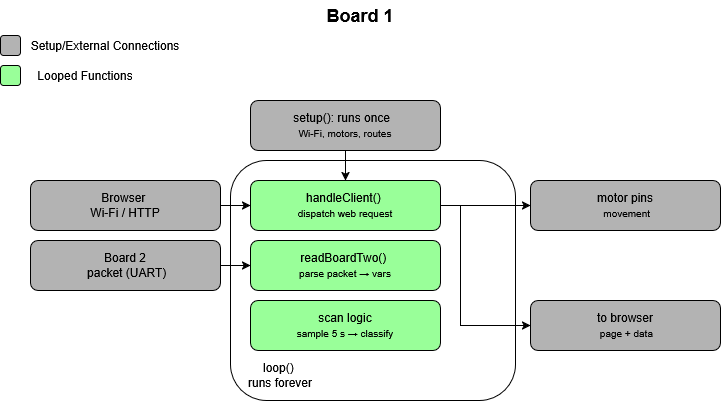
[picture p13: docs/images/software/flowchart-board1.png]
Board 1 software flowchart


---

## 10.2 Why two boards

It is worth being honest about this: a single Metro M0 could realistically have run the entire system.

- The 48 MHz Cortex-M0+ has ample compute for this workload.
- The time-sensitive inputs are already protected by hardware — infrared counting on an interrupt, the radio read into an interrupt-driven UART buffer, the motors on hardware PWM.
- Board 1 alone, running Wi-Fi, the web server, the motors and classification, uses only about **18% of its RAM and 38% of its flash**.

A working single-board implementation exists in this repository at [`Lonely_Board/`](../Lonely_Board/).

Two boards were chosen anyway, for three reasons:

### Timing isolation

Serving the page over the WINC1500 blocks the processor in bursts. Keeping all sensing on a board that never stops for Wi-Fi makes measurement timing **independent of network activity** — the web server can never stall a reading. This mirrors the standard practice of separating real-time from best-effort tasks.

This is the strongest of the three arguments. The infrared subsystem counts 50 µs pulses over 200 ms windows; a multi-millisecond Wi-Fi stall inside one of those windows would corrupt the rate directly.

### Parallel development

Splitting sensing from control and UI let the two halves be built and tested independently, which suited how the team divided the work.

### Added capability

The working inter-board link is a more capable design than a single sketch, and the clean split keeps each board's code simple and focused.

**The trade-off accepted** is the modest extra complexity of the inter-board connection and a small increase in weight — both of which proved manageable.

---

## 10.3 Choosing how the boards talk

Six options were considered:

| Option | Verdict |
|---|---|
| `Serial1`, two-way | **Rejected** — pin 0 (RX) is taken by the radio on Board 2 |
| `SoftwareSerial` (bit-banged UART) | **Rejected** — not supported on the SAMD21; it compiles but does not work |
| Wi-Fi (UDP/TCP between boards) | **Rejected** — adds latency, unreliable in a crowded exhibition hall, and overkill for a few bytes |
| I²C | **Rejected** — the magnetometer already owns the I²C bus |
| SPI | **Rejected** — the Wi-Fi shield already owns the SPI bus, and the bandwidth is not needed |
| **SERCOM hardware UART (one-way)** | **Selected** |

The pattern in those rejections is that every default peripheral was already committed to something else. SERCOM is what remained — and it turned out to be the right answer rather than merely the surviving one.

---

## 10.4 SERCOM UART

The SAMD21 has **six SERCOM (Serial Communication) modules**, each of which can act as a UART, SPI or I²C peripheral and be mapped to non-default pins. This is the manufacturer's intended mechanism for adding an extra hardware UART, so it gives a properly buffered, interrupt-driven port without the unreliability of software bit-banging.

**SERCOM1** was mapped to pins 10 (TX) and 11 (RX) using the `UART` class and `pinPeripheral()`, which tells the chip to route those pins through SERCOM rather than treating them as ordinary GPIO.

The physical link is two conductors:

```
Board 2 pin 10 (TX)  ──────▶  Board 1 pin 11 (RX)
Board 2 GND          ───────  Board 1 GND
```

It is one-way because Board 2 only ever sends; there is no need for a return wire.

> **An accident that turned out well.** Pin 0 on Board 1 was found to be dead, so receiving on pin 11 via SERCOM was necessary regardless. The flexible pin mapping turned a potential hardware blocker into a one-line firmware change.

---

## 10.5 Packet format

**Continuous streaming** was chosen over a request-response scheme. Request-response would need two-way communication, and Board 2 has no spare RX pin — the radio owns pin 0.

Board 2 therefore sends a packet once per second, and Board 1 parses every packet as it arrives, continuously updating the live sensor values shown to the operator. The scan state only decides whether those readings are *also* accumulated for classification.

Each packet is one newline-terminated CSV line:

```
AGE:3.82,IR:539,IRC:547,IRCO:93,US:1,MAG:DOWN
```

| Field | Meaning |
|---|---|
| `AGE` | Rock age in billions of years, decoded from the radio |
| `IR` | Raw infrared pulse rate in Hz |
| `IRC` | IR classification — the nearer of the two expected rates (312 or 547), or 0 for no rock |
| `IRCO` | IR confidence, 0–100% |
| `US` | Ultrasonic presence: 1 or 0 |
| `MAG` | Magnetic direction: `UP`, `DOWN` or `UNKNOWN` |

Board 1 reads all six fields. It uses `IRC` for the infrared high/low decision and the averaged `IRCO` as the infrared confidence, alongside `AGE`, `US` and `MAG`.

The format was chosen because it is easy to read and debug, easy to extend, and **self-synchronising**: the newline terminator means any partial packet — for example if Board 1 powers up mid-message — is simply discarded rather than misparsed.

**9600 baud is far more than enough.** At ~45 bytes per packet and 1 Hz, the link uses about **5%** of the ~960 bytes/s available.

---

## 10.6 Implementation

### Board 2 — sensing

Board 2 runs **entirely non-blocking**, so reading the radio buffer, polling the ultrasonic pin, reading the magnetometer over I²C and sending packets never hold each other up. Infrared uses a hardware interrupt on pin 2, so pulses are caught no matter what the loop is doing.

Keeping all of this on a board with no Wi-Fi workload is the timing isolation described above — sensing is never disturbed by bursts of network activity.

### Board 1 — control

Board 1 hosts the web interface, drives the motors through the H-bridge, and runs rock classification on the data it receives.

---

## 10.7 Rock classification

The four rock types each map to a unique combination of the three type-sensor outputs:

| Rock type | Infrared | Ultrasound | Magnetic |
|---|---|---|---|
| **Basaltoid** | 547 Hz | Present | Down |
| **Gravion** | 312 Hz | Absent | Down |
| **Regolix** | 312 Hz | Present | Up |
| **Lunarite** | 547 Hz | Absent | Up |

During a scan, Board 1 takes a sample roughly every **200 ms across a 5-second window** — about 25 samples.

- The two binary sensors (**ultrasonic** and **magnetic**) are resolved by **majority vote** over those samples.
- The **infrared** high/low decision is taken from Board 2's own IR classification (`IRC`).
- The three results are looked up against the table above to give the rock type.

### Confidence

The confidence figure shown to the operator is computed from the readings themselves:

| Sensor | Score |
|---|---|
| Ultrasonic | How one-sided the vote was — unanimous = 100%, an even split = 0% |
| Magnetic | Same |
| Infrared | Board 2's `IRCO` confidence, averaged across the scan |

The three are averaged into an overall percentage. A separate count reports how many of the three sensors were **clearly decisive**.

A clean rock therefore reads at high confidence, while a borderline or flickering sensor lowers the figure honestly — which is the point. A classifier that always reported certainty would be worse than useless here, because the operator would have no basis for deciding when to rescan.

A reference implementation of the lookup is in [`software/rock_classification.md`](../software/rock_classification.md).

---

## 10.8 Development setup

Both boards are kept as **separate PlatformIO projects** (`platform = atmelsam`, `framework = arduino`) in this shared repository.

```ini
lib_ignore = Adafruit TinyUSB Library
```

This directive is **required**. Without it the build hits a USB symbol conflict with the WiFi101 stack. It is present in both projects' `platformio.ini` and should not be removed.

---

[← Web interface](09-web-interface.md) · [Documentation index](README.md) · [Repo home](../README.md) · [Next: Cost and bill of materials →](11-cost-and-bom.md)

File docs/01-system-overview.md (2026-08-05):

[← Documentation index](README.md) · [Repo home](../README.md) · [Next: Infrared sensing →](02-infrared.md)

# 1. System Overview

## 1.1 Project objectives

The aim of the project was to design and build a remotely controlled lunar rover capable of manoeuvring a lunar terrain and surveying the rocks in the area. The rover determines each rock's age and type by detecting the radio, infrared, magnetic and ultrasonic signals the rock emits.

The rover is tested in a lab-controlled environment on a smooth surface. Large rocks must be driven around; smaller rocks are the scan targets. Two constraints shaped the whole design:

- **Mass under 750 g.** This ruled out heavier structural materials and pushed the chassis towards thin 3D-printed PLA plates.
- **3.3 V logic throughout.** The Metro M0's digital input pins are not 5 V tolerant, so every analogue front-end runs from the Metro's regulated 3.3 V rail. No level shifting or protection dividers are needed anywhere between a sensor board and a microcontroller pin.

## 1.2 The four rock types

Each rock transmits its age over radio, and encodes its type in three further signals:

| Rock type | Infrared pulse rate | Ultrasound (40 kHz) | Magnetic polarity |
|---|---|---|---|
| **Basaltoid** | 547 Hz | Present | Down |
| **Gravion** | 312 Hz | Absent | Down |
| **Regolix** | 312 Hz | Present | Up |
| **Lunarite** | 547 Hz | Absent | Up |

Read as a truth table, any **two** of the three columns uniquely identify all four types. The rover measures all three anyway. The redundancy is deliberate: the third sensor cross-checks the other two, and the degree of agreement between them becomes the **confidence score** shown to the operator. A rock that reads cleanly scores high; one where a sensor flickers scores low, which is precisely the signal telling the operator to reposition and rescan.

> Rock ages arrive as four ASCII characters beginning with `#`. `#123` means 1.23 billion years.

## 1.3 System architecture

System diagram of the rover

The system splits across two Adafruit Metro M0 Express boards (SAMD21, 48 MHz Cortex-M0+):

**Board 2 — sensing.** Runs all four sensor subsystems and nothing else. Infrared pulses are counted on a hardware interrupt, the demodulated radio bitstream is read by the hardware UART on pin 0, the ultrasonic envelope is polled as a digital level, and the magnetometer is read over I²C. Once a second it packs everything into one CSV line and sends it to Board 1.

**Board 1 — control.** Carries the WINC1500 Wi-Fi shield, serves the mission control web page, drives the two motors through an H-bridge, and runs the rock classification over the readings streamed from Board 2.

The link between them is a one-way hardware UART on SERCOM1 at 9600 baud — two wires, TX to RX plus a shared ground.

```mermaid
sequenceDiagram
    participant Rock
    participant B2 as Board 2 (sensing)
    participant B1 as Board 1 (control)
    participant OP as Operator browser

    loop every 1 s
        Rock-->>B2: IR pulses / 89 kHz radio / 40 kHz tone / magnetic field
        B2->>B1: AGE:3.82,IR:539,IRC:547,IRCO:93,US:1,MAG:DOWN
        B1-->>B1: update live values
    end

    loop every 1 s
        OP->>B1: GET /sensors
        B1-->>OP: current readings
    end

    OP->>B1: GET /scan
    activate B1
    Note over B1: 5 s window, sample every 200 ms<br/>majority vote + confidence
    B1-->>OP: rock type, age, confidence
    deactivate B1
```

## 1.4 Signal chain summary

Every analogue subsystem follows the same broad shape — pick up a weak signal, amplify it hard, reduce it to something a digital pin can read — but the details differ enough to be worth stating side by side:

| | Infrared | Radio | Ultrasound |
|---|---|---|---|
| Sensor | SFH300 phototransistor | 120-turn ferrite coil | Prowave 400SR160 |
| Raw signal | ~µA current pulses | tens of mV at 89 kHz | ~150 mV pk-pk at 40 kHz |
| Amplifier | Inverting, ×100 (MCP6022) | Non-inverting, ×101 (MCP6022) | Two non-inverting stages, ×34 each (MCP6022) |
| Filtering | Band-pass, 159 Hz – 48 kHz | Tuned LC at 89 kHz | Transducer's own 2.5 kHz bandwidth |
| Digitising | LM393 comparator | LM393 comparator / Schmitt trigger | None — envelope drives the pin directly |
| Read by | Hardware interrupt, pin 2 | Hardware UART, pin 0, 600 baud | `digitalRead()` with a debounce counter |

The magnetic subsystem is the exception: the SEN0619 module performs its own amplification and conversion and reports over I²C, so it needs no analogue circuitry at all.

## 1.5 Where things live in this repository

| Concern | Location |
|---|---|
| Flight firmware, Board 1 | [`Full_Board_Code/Board 1/`](../Full_Board_Code/Board%201/) |
| Flight firmware, Board 2 | [`Full_Board_Code/Board 2/`](../Full_Board_Code/Board%202/) |
| Single-board prototype | [`Lonely_Board/`](../Lonely_Board/) |
| Per-sensor test firmware | [`sensing/`](../sensing/) |
| KiCad projects and Gerbers | [`sensing/PCBs/`](../sensing/PCBs/) |
| Web interface firmware | [`software/Website/rover_website/`](../software/Website/rover_website/) |

---

[← Documentation index](README.md) · [Repo home](../README.md) · [Next: Infrared sensing →](02-infrared.md)

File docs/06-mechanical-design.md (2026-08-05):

[← Magnetic field sensing](05-magnetic-field.md) · [Documentation index](README.md) · [Repo home](../README.md) · [Next: Movement and control →](07-movement-and-control.md)

# 6. Mechanical Design — Chassis and Sensor Arm

**Designed in:** Fusion 360
**Printed in:** PLA
**Actuator:** SER0047 metal-geared servo

---

## 6.1 Overview

The chassis is the structural core of the rover, built as a **two-plate stack** with each plate handling a distinct set of functions:

| Plate | Carries |
|---|---|
| **Lower (base) plate** | Drive motors, motor driver module, power supply, Board 1 |
| **Upper (sensor) plate** | Sensor PCBs, radio antenna arm, rotating sensor arm, Board 2 |

The two plates are separated by spacers, with wiring running between them.

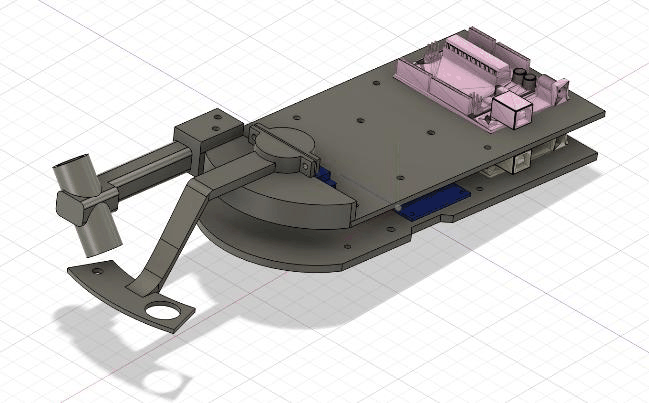
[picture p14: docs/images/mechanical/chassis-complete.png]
Complete chassis design


---

## 6.2 Requirements

The chassis must:

- carry both plates, the rotating and radio arms, the power supply, both boards and all circuitry **without measurable flex**;
- let the sensor arm sweep across a rock **without turning the whole rover**;
- provide rigid, accurately placed mounting points so nothing shifts under motor vibration.

The most important constraint, though, is **noise isolation**. DC-motor commutation and PWM transients must not couple into the sensors. Two subsystems are particularly exposed:

- **The magnetometer**, which responds directly to the motors' changing magnetic field.
- **The radio**, which — although its 89 kHz tuned coil rejects most out-of-band noise — can still pick up interference through its high gain.

Both are therefore kept physically separated from the motors. This requirement, more than any other, dictated the layout.

---

## 6.3 Dual-plate layout

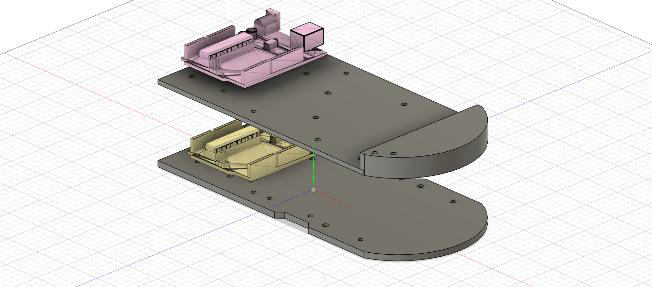
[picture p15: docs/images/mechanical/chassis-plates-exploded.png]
Base plate and sensor plate


The PCBs holding the sensor circuitry are screwed directly to the sensor plate through mounting holes, and both Metro boards are mounted at the rear of the chassis to keep the inter-board wiring short and easy to route.

### Material choice

The department offered **PLA** and **TPU**. TPU was rejected because its flexibility would let the plates deform under load and during motion — unacceptable for a structural frame that must hold components tightly in place.

PLA was chosen despite being relatively brittle and prone to some flex under sustained load. That limitation was addressed by making the plates thick enough to stay stiff rather than sag under the components mounted on them.

### Dimensions

| Parameter | Value | Reasoning |
|---|---|---|
| Plate width | 95 mm | — |
| Plate length | 205 mm | Arced front end |
| Plate separation | 35 mm | Clears the tallest component below while keeping sensors at a useful height |
| Base plate thickness | 4 mm | Supports motors *and* the entire sensor plate above it |
| Sensor plate thickness | 3 mm | Carries only lighter circuitry and the arm — saves weight and print time |

Both plates share an almost identical outline so they stack evenly, with the base plate including notches for the motors. Component dimensions were measured with callipers so that mounting holes and cut-outs in the CAD model matched each part precisely.

> **The 35 mm separation could not be set in CAD beforehand.** The wheels caused the chassis to tilt, making the true ground clearance hard to predict. The spacing was measured directly once both plates were printed and the wheels fitted — a case where the physical build had to inform the model rather than the other way round.

---

## 6.4 Sensor mounting

The sensor plate holds **two separate mounting structures**: a fixed arm for the radio antenna, and a rotating arm carrying the other three sensors. Keeping them separate was deliberate, for two reasons:

1. **The radio does not need aiming.** Its range is much larger than the other sensors', so there is no benefit to sweeping it across the rock.
2. **The radio antenna is heavy.** It uses an iron core with the inductor coil wound around it, and a PLA rotating arm would not reliably support that weight while turning.

Giving the radio its own fixed, sturdy arm removes both problems at once.

### Radio arm

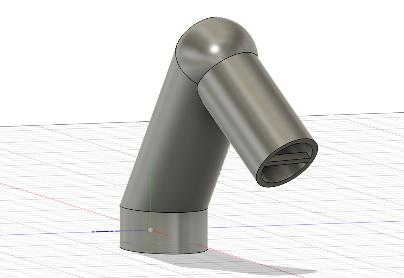
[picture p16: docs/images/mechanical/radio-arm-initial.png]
Radio antenna holder — initial version


The arm is angled so the coil points **downward toward the rock** rather than straight ahead, which matters because induced EMF depends on the angle between transmitting and receiving coils (see [Radio § reflections](03-radio.md#38-reflections)). Because the radio's detection range is relatively large, the antenna does not need to sit close to the rock.

An early version was **glued rather than screwed** and, once test-fitted, sat too high above the rock:

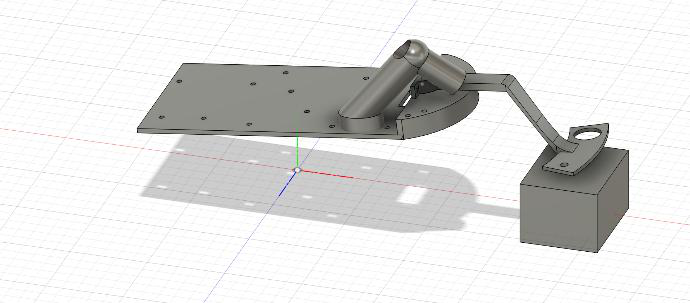
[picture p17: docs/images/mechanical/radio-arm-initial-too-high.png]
Radio antenna sitting too far from the rock


The redesign is screwed down through mounting holes and sits at the correct height:

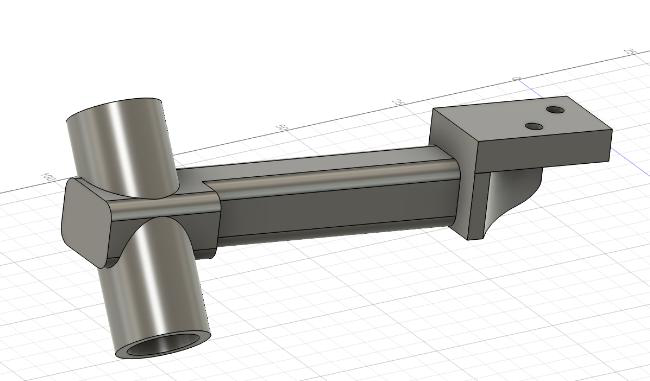
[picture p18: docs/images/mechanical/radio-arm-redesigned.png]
Redesigned radio arm

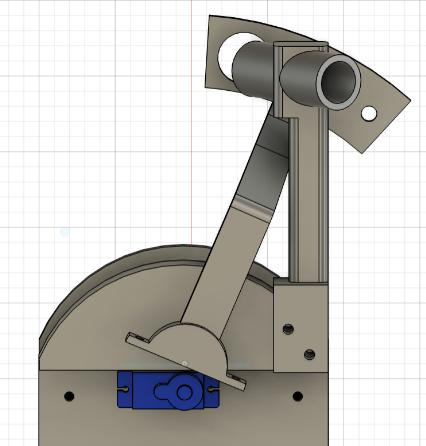
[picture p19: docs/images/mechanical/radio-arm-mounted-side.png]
Radio arm mounted on the sensor plate


Its only cost is restricting the sensor arm's rightward sweep to **23° from centre** — which still covers enough of the rock to be useful:

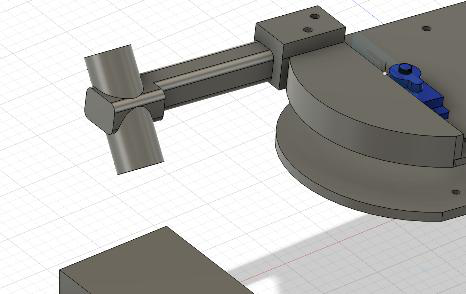
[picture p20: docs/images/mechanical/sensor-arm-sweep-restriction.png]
Sensor arm sweep restriction


### Sensor arm

The rotating arm carries the three remaining sensors and sweeps them across the rock, so each measurement can be taken while the rover itself stays still.

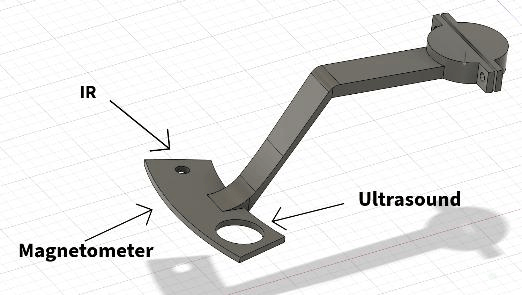
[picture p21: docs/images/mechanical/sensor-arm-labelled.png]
Sensor arm with sensors labelled


The magnetometer is fixed to the underside of the arm; the infrared and ultrasonic sensors mount through holes spaced along it, so all three point down toward the rock.

**Why sweep at all?** The infrared and magnetic signals are strongest at one point on the rock and very weak elsewhere. Sweeping lets each sensor find the position where its signal is strongest, rather than depending on a single fixed reading that might miss the source entirely or return a corrupted value.

### Sensors follow the sweep arc

Rather than sitting in a straight line, the sensors are arranged **along the arc the servo sweeps the arm through**, so that each one's path crosses the same target point near the centre of the rock.

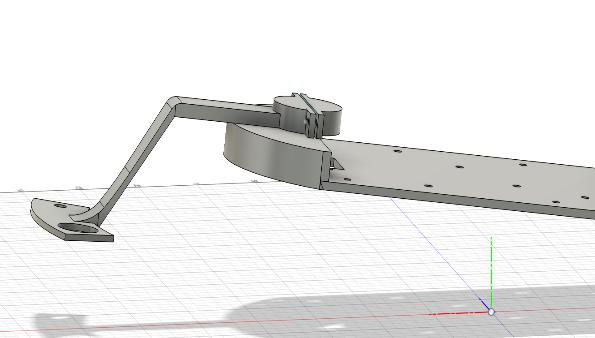
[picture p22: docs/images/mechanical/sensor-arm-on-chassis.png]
Sensors arranged along the sweep arc


This matters most for the infrared and magnetic sensors, which must pass very close to the signal source to record a reliable value. A straight-line arrangement would put the outer sensors on paths that never cross the target.

### Servo selection

The arm is driven by a servo mounted on the sensor plate, with its wires running down to the board on the base plate. The **SER0047** was chosen over the cheaper plastic-geared servos initially available, for three reasons:

| Reason | Detail |
|---|---|
| **Torque** | ~0.15 N·m stall torque at 6 V — enough to move the loaded arm and hold it steady against its own weight, even at the ends of the sweep |
| **Durability** | Metal gears, far more resistant to wear than plastic |
| **Power** | Low current draw, so it runs from the rover's existing supply without a separate source |

### Arc support platform

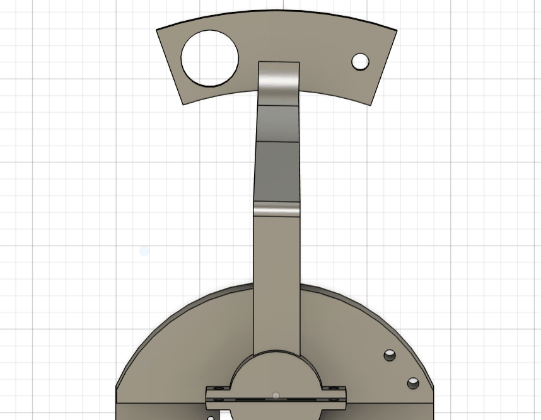
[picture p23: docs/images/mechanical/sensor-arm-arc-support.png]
Arced support platform under the sensor arm


The sensor plate is raised on a platform with an **arced upper surface** that follows the path the arm traces as it rotates. The arm therefore stays supported at every angle rather than overhanging at the extremes.

This does two things: it holds the arm at a **consistent height above the rock across the whole sweep**, giving more consistent readings; and it takes the arm's weight off the servo, so the motor does not have to support the arm on its own.

---

## 6.5 Photographs still needed

The CAD renders above document the design intent. Photographs of the built rover would show how it actually turned out — the two are not the same thing, and a reader evaluating this project will want both.

> **📸 `images/mechanical/rover-assembled.jpg`**
> The fully assembled rover, three-quarter view, showing both plates, wheels, arms and wiring. This is the single most valuable missing image — it belongs at the top of the root README.

> **📸 `images/mechanical/rover-side-profile.jpg`**
> Side-on view showing the 35 mm plate separation and the sensor arm's height above the ground.

> **📸 `images/mechanical/rover-scanning-rock.jpg`**
> The rover parked at a rock mid-scan, with the sensor arm swept over it. Demonstrates the working geometry better than any render.

> **📸 `images/mechanical/sensor-arm-built.jpg`**
> Close-up of the printed sensor arm with the IR, ultrasonic and magnetometer sensors fitted.

> **📸 `images/mechanical/chassis-underside.jpg`**
> Underside of the base plate showing motor mounting and the notches.

See [images/README.md](images/README.md) for the complete list across all subsystems.

---

[← Magnetic field sensing](05-magnetic-field.md) · [Documentation index](README.md) · [Repo home](../README.md) · [Next: Movement and control →](07-movement-and-control.md)

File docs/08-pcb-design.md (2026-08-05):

[← Movement and control](07-movement-and-control.md) · [Documentation index](README.md) · [Repo home](../README.md) · [Next: Web interface →](09-web-interface.md)

# 8. PCB Design

**Tool:** KiCad
**Boards:** two — radio, and infrared + ultrasound combined
**Files:** [`sensing/PCBs/`](../sensing/PCBs/)

---

## 8.1 Overview

Moving from breadboard to PCB is the step that turns a prototype into reliable hardware. Two boards were produced:

| Board | Contains | Source |
|---|---|---|
| **Radio** | Antenna tuning, amplifier, envelope detector, comparator | [`sensing/PCBs/Radio PCB/`](../sensing/PCBs/Radio%20PCB/) |
| **IR + Ultrasound** | Both analogue chains, sharing a board | [`sensing/PCBs/IR + ultrasound/`](../sensing/PCBs/IR%20+%20ultrasound/) |

**Why two boards rather than one?** The split gives a clean boundary between subsystems, simplifies debugging, and allowed the two chains to be developed and tested independently.

It is worth being explicit that electromagnetic interference was **not** the driving factor. Even the highest frequency involved — the 89 kHz radio carrier — is low by EMI standards. The split was made for practical rather than electrical reasons.

**No PCB was needed for magnetic sensing.** The SEN0619 module delivers a digital output over I²C and connects directly to the Metro board (see [Magnetic field sensing](05-magnetic-field.md#54-integration)).

### Supply and output

The boards are powered from **3.3 V rather than 5 V**, because the Metro M0 operates on 3.3 V logic and applying 5 V to its digital inputs would exceed their absolute maximum rating.

This choice pays off twice. Powering the op-amp and comparator from 3.3 V means their output **can never exceed the Metro's input limit**, even at full rail-to-rail swing — so no potential divider or protection circuitry is needed between the PCB output and the microcontroller.

The output header exposes the UART signal, 3.3 V and GND, allowing direct connection to the Metro M0 while leaving room for test equipment and additional components.

---

## 8.2 Radio board

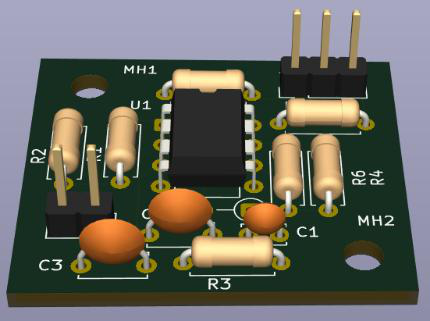
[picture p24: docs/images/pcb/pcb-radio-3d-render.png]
Radio PCB, 3D render


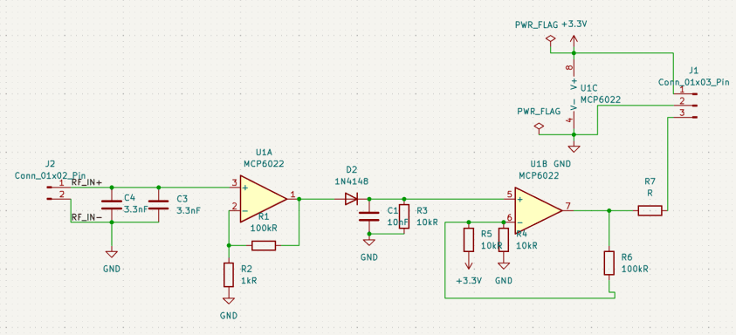
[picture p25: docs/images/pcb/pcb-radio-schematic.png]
Radio schematic


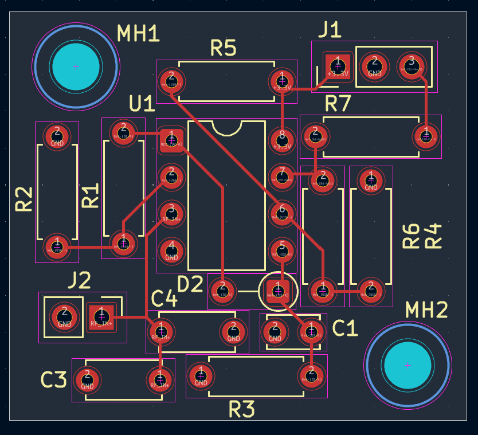
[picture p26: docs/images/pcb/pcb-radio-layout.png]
Radio board layout


Manufacturing files: [`sensing/PCBs/Radio final PCB/`](../sensing/PCBs/Radio%20final%20PCB/) (Gerbers and drill files).

---

## 8.3 Infrared + ultrasound board

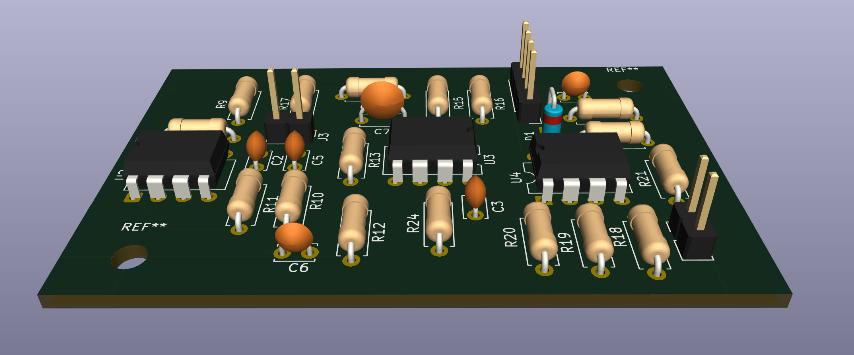
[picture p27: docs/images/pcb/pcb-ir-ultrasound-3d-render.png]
IR + ultrasound PCB, 3D render


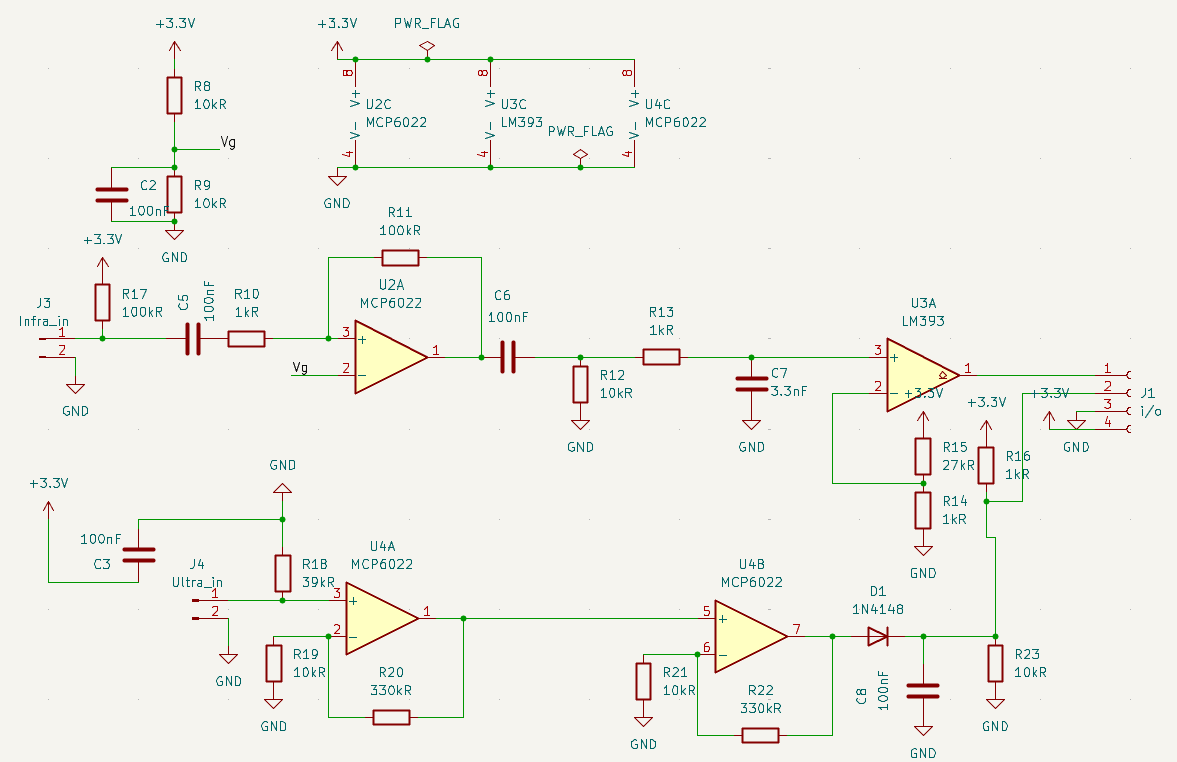
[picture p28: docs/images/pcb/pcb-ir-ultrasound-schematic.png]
IR + ultrasound schematic


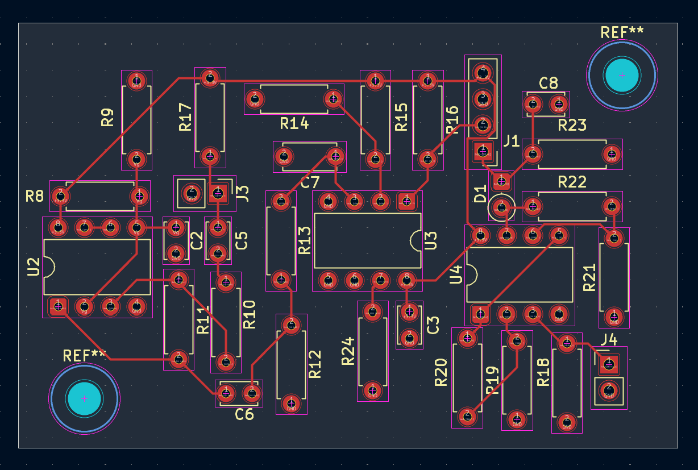
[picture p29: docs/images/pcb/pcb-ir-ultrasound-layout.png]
IR + ultrasound board layout


Manufacturing files: [`sensing/PCBs/Infrared final pcb/`](../sensing/PCBs/Infrared%20final%20pcb/).

---

## 8.4 Unused op-amp and comparator channels

Both the **MCP6022** and **LM393** are dual-channel devices, and only one channel of each is used.

The unused channels cannot simply be left floating. Unconnected inputs pick up noise and cause unpredictable oscillation, which then couples interference into the *active* channel through the shared supply — degrading the very circuit the device is there to serve.

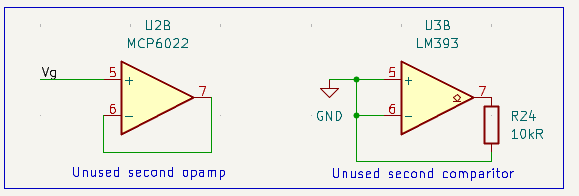
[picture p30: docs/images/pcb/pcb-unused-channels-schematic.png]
Unused op-amp and comparator channels


| Device | Channel | Treatment |
|---|---|---|
| MCP6022 | U2B | Configured as a **voltage follower**, non-inverting input tied to the `Vg` bias voltage — holds the output at a stable DC level |
| LM393 | U3B | Both inputs tied to **GND**, with a 10 kΩ pull-up (R24) on the open-collector output to prevent it floating |

Both follow standard practice for handling unused amplifier channels.

---

## 8.5 Footprint selection

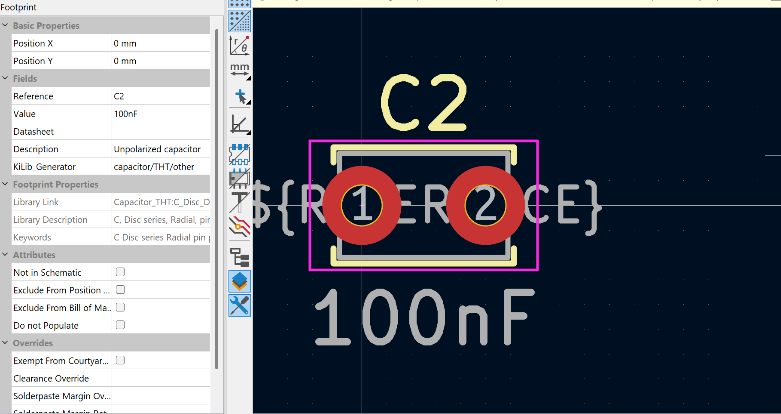
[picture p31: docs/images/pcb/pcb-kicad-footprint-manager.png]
KiCad footprint manager


Choosing the right footprint for each component is easy to get wrong and expensive to discover after manufacture. Physical component dimensions were measured with a **Vernier calliper** and matched against the available KiCad libraries rather than assumed from part numbers.

---

## 8.6 Layout rules applied

The layout was created by defining the board outline, placing components, and then routing.

### Avoiding right-angle traces

Right-angle traces cause electromagnetic fields to bunch at the corner, generating interference and acting as unintended antennas. **45° routing** was used throughout.

### Ground plane

A copper ground plane was applied to the back layer, providing a low-impedance return path for current and shielding against electromagnetic interference.

### Trace width

A uniform trace width was used throughout. Given the low current levels in the analogue signal chain, a single default width was sufficient everywhere without risk of overheating.

### Avoiding long parallel tracks

Long parallel runs were minimised to reduce capacitive coupling between signals, preserving signal integrity in the analogue chain.

### Component placement

Components were placed to keep signal paths short and ordered logically from input to output, reducing trace length and minimising interference.

---

## 8.7 Manufacturing files

| Board | KiCad project | Gerbers |
|---|---|---|
| Radio | [`sensing/PCBs/Radio PCB/`](../sensing/PCBs/Radio%20PCB/) | [`sensing/PCBs/Radio final PCB/`](../sensing/PCBs/Radio%20final%20PCB/) |
| IR + ultrasound | [`sensing/PCBs/IR + ultrasound/`](../sensing/PCBs/IR%20+%20ultrasound/) | [`sensing/PCBs/Infrared final pcb/`](../sensing/PCBs/Infrared%20final%20pcb/) |
| Demo board | [`sensing/PCBs/Demo pcb/`](../sensing/PCBs/Demo%20pcb/) | [`sensing/PCBs/Final files greber/`](../sensing/PCBs/Final%20files%20greber/) |

Each Gerber set contains front and back copper, front and back solder mask, front silkscreen, edge cuts, and both plated and non-plated drill files — everything a fabricator needs.

---

## 8.8 Photographs still needed

> **📸 `images/pcb/pcb-radio-populated.jpg`**
> The manufactured radio board with components soldered in place.

> **📸 `images/pcb/pcb-ir-ultrasound-populated.jpg`**
> The manufactured IR + ultrasound board, populated.

> **📸 `images/pcb/pcbs-mounted-on-chassis.jpg`**
> Both boards screwed to the sensor plate and wired to the Metro — showing the transition from the renders above to the finished rover.

---

[← Movement and control](07-movement-and-control.md) · [Documentation index](README.md) · [Repo home](../README.md) · [Next: Web interface →](09-web-interface.md)

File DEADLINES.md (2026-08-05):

# Project Deadlines
This file tracks the individual task deadlines for all team members working on the Lunar-ICE project.

## Team Members & Their Deadlines
| Member | Task | Target Completion Date | Status |
|---|---|---|---|
| Shivang | Ultrasound | YYYY-MM-DD | Not Started |
| Tibor | Movement | YYYY-MM-DD | Not Started |
| Tunir | Infrared | YYYY-MM-DD | Not Started |
| Junhao | Infared (working with Tunir) | YYYY-MM-DD | Not Started |
| Yangping | Magnetic | YYYY-MM-DD | Not Started |
| Qais | Radio | YYYY-MM-DD | Not Started |

## Task 1 — Research & Feasibility (Due: 2026-05-14 @ 13:00)
Each team member is required to research their designated sensor/component and report back with the following:
1. **Understand the sensing principle** — how does your sensor detect its target, and how does that raw signal get converted into a usable digital output?
2. **Identify possible sensors** — research available options on the market that could fulfil the requirement
3. **Cost analysis** — provide estimated costs for each sensor option identified
4. **Summary report** — compile your findings and be ready to present them to the team by the deadline

## Instructions
1. **Add your task description** in the Task column (e.g., "Implement authentication", "Design UI mockups", etc.)
2. **Set your deadline** in YYYY-MM-DD format (e.g., 2026-06-30)
3. **Update Status** as you progress: "Not Started" → "In Progress" → "Complete" or mark as "Blocked"

## Status Legend
- ✅ **Complete** - Task finished and merged/integrated
- 🔄 **In Progress** - Currently working on this task
- ⏳ **Not Started** - Task not yet begun
- 🚫 **Blocked** - Task blocked, waiting on dependencies

---
**Last Updated:** 2026-05-13

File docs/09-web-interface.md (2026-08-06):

[← PCB design](08-pcb-design.md) · [Documentation index](README.md) · [Repo home](../README.md) · [Next: Dual-board architecture →](10-dual-board-architecture.md)

# 9. Web Interface — Mission Control

**Served by:** Board 1, via a WINC1500 Wi-Fi shield
**Source:** [`software/Website/rover_website/src/main.cpp`](../software/Website/rover_website/src/main.cpp)
**Standalone preview:** [`software/eeerover_mission_control_demo.html`](../software/eeerover_mission_control_demo.html)

---

## 9.1 Overview

The rover is controlled and monitored entirely through a web page, so the operator needs nothing more than a browser on the same Wi-Fi network. Board 1 serves the page; the operator opens the rover's IP address, which Board 1 prints over the serial monitor when it joins the network.

A browser-based interface was chosen because it works on any laptop or phone and allows a responsive display to be built without writing a separate desktop program.

Mission control interface

---

## 9.2 What the page shows, and why

The centre of the screen holds a stylised animated graphic of the rover. It is **purely aesthetic**, giving the interface identity — and it can afford the prime position precisely because everything around it stays readable.

Directly below sits the **rock classification panel**: type, age and scan confidence. This is the mission's real output. The confidence figure is what tells the operator whether to trust a result or rescan it.

Arranged around these are:

| Element | Purpose |
|---|---|
| Live sensor readings | IR rate, ultrasonic present/absent, magnetic direction, radio age — what the rover is picking up right now |
| Scan log | Timestamped record of scans and identifications |
| Link health | Latency and packets received, so a dropped connection is immediately obvious |
| Drive controls | Mode selector and on-screen movement buttons |

Everything besides the central graphic is either a key output or a way to judge that the system is working.

---

## 9.3 How the page talks to the rover

Reloading the whole page on every button press would flicker and briefly block further commands. Instead the page uses JavaScript `fetch()` calls, which send a request to Board 1 in the background and leave the page untouched — only the rover reacts.

The same mechanism refreshes the readings: once a second the page fetches the latest sensor values and updates the numbers on screen, with no operator input.

**Why once a second?** Two independent reasons converge on the same figure:

1. It matches how often Board 2 sends fresh data (~1 Hz). Polling faster would just re-fetch identical values.
2. Board 1 serves only one request at a time, so a modest poll rate keeps sensor fetches from queuing behind drive commands — the same class of problem that caused the [gamepad latency bug](07-movement-and-control.md#75-the-latency-problem-and-the-fix).

---

## 9.4 Serving the page

The whole Board 1 program fits comfortably in flash: about **38% of 256 KB** (~100 KB, mostly the Wi-Fi libraries and the page text) and only about **18% of 32 KB RAM**. The page is held as a string in flash, not RAM.

The real constraint is not storage but **transmission**. The WINC1500 module can only push a limited amount of data per transfer, and attempting to send the whole page in one go **crashes the driver**.

Board 1 therefore streams the page to the browser in **500-byte chunks**, which the browser reassembles. The 500-byte figure was arrived at by testing rather than derived — larger chunks were unreliable, smaller ones needlessly slow.

---

## 9.5 Drive control

The page can drive the rover from the keyboard (WASD) or on-screen buttons, each sending a `fetch()` to a movement route on Board 1, which then sets motor directions and speeds.

These controls were used mainly during early testing. The rover is now driven with a connected game controller — see [Movement and control](07-movement-and-control.md#74-gamepad-control).

---

## 9.6 Scanning a rock

Two facts shape the scan design:

- Sensor readings taken while the rover is moving between rocks are meaningless.
- A single instantaneous reading is easily thrown off by noise.

Classification is therefore **on demand**. The operator stops at a rock and presses **SCAN ROCK**, which starts a 5-second window on Board 1.

```mermaid
flowchart TD
    A["Operator presses SCAN ROCK"] --> B["Board 1 opens a 5 s window"]
    B --> C["Sample every ~200 ms<br/>(~25 samples)"]
    C --> D["Ultrasonic: majority vote"]
    C --> E["Magnetic: majority vote"]
    C --> F["Infrared: Board 2's IRC verdict"]
    D & E & F --> G["Look up combination<br/>in the rock table"]
    G --> H["Report type + age + confidence"]
```

Over that window Board 1 collects repeated readings, settles the two on/off sensors (ultrasonic and magnetic) by **majority vote**, takes Board 2's infrared verdict, then looks the combination up to identify the rock.

The **confidence** shown is worked out from how decisive each sensor was during the scan. A clean rock reads high; a flickering one reads low. That is exactly what tells the operator whether to rescan. Full detail in [Dual-board architecture](10-dual-board-architecture.md#107-rock-classification).

---

## 9.7 Endpoints

| Route | Purpose |
|---|---|
| `GET /` | Serve the mission control page (chunked) |
| `GET /forward`, `/left`, `/right`, `/stop`, … | Discrete movement commands (keyboard and on-screen buttons) |
| `GET /drive?left=L&right=R` | Analogue drive from the gamepad; sign sets direction, magnitude sets PWM |
| `GET /sensors` | Current sensor values as parsed from Board 2's last packet |
| `GET /scan` | Begin a 5-second classification window |

---

[← PCB design](08-pcb-design.md) · [Documentation index](README.md) · [Repo home](../README.md) · [Next: Dual-board architecture →](10-dual-board-architecture.md)

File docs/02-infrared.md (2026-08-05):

[← System overview](01-system-overview.md) · [Documentation index](README.md) · [Repo home](../README.md) · [Next: Radio sensing →](03-radio.md)

# 2. Infrared Sensing

**Measures:** rock type, via pulse rate
**Output:** 312 Hz or 547 Hz, plus a confidence figure
**Firmware:** [`sensing/Infrared/ir_test_code/`](../sensing/Infrared/ir_test_code/) (test), [`Full_Board_Code/Board 2/`](../Full_Board_Code/Board%202/) (flight)

---

## 2.1 The signal

Each rock emits infrared pulses **50 µs wide** at one of two average rates: **312 Hz** or **547 Hz**. The emission follows a Poisson distribution, so the pulses are not evenly spaced and the measured rate is approximate rather than exact. Any measurement scheme therefore has to average over a reasonable window rather than time a single interval.

Pulses are picked up with an **SFH300 phototransistor**, chosen because:

- its spectral response covers the 950 nm wavelength the rock emits;
- it is low cost and was readily available;
- it operates from a 3.3 V supply;
- it is available in a package that suits both breadboard and PCB.

---

## 2.2 Design

### Virtual ground

The circuit runs from a single 3.3 V supply, so there is no negative rail for the op-amp output to swing into. A virtual ground fixes this.

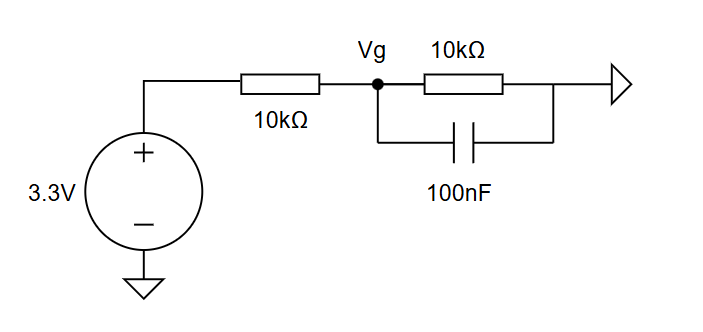
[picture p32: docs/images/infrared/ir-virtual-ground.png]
Virtual ground circuit


Two 10 kΩ resistors form a potential divider producing approximately 1.5 V at `Vg`, which becomes the new baseline in place of 0 V. The 100 nF capacitor shunts AC to ground so that only a clean DC reference reaches the op-amp.

3.3 V was chosen as the supply because it is the maximum voltage the Metro M0's input pins tolerate — powering the analogue chain from the same rail means its output can never exceed that limit, however hard it clips.

### Modelling the phototransistor

Before building anything, the phototransistor was simulated as a current source driving an NPN transistor:

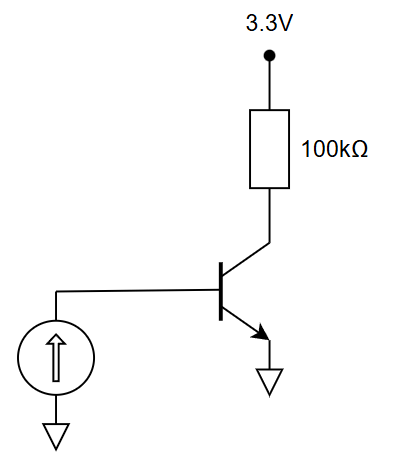
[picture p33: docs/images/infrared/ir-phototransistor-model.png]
Phototransistor simulation model


The source parameters mirror the real signal: **1 µA** amplitude (representing the sensor covered by the rock), **50 µs** on-time to match the pulse width, and a **3.2 ms** period to give a 312 Hz rate. The NPN converts the current pulses into voltage pulses that can then be amplified.

### Amplification

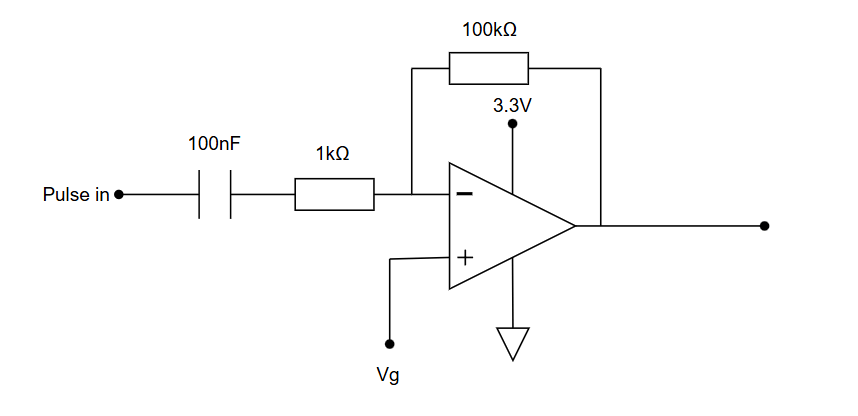
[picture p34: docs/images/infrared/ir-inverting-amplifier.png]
Inverting amplifier, gain 100


An inverting amplifier built around the **MCP6022** provides a gain of 100:

$$A = \frac{R_1}{R_2} = \frac{100\ \text{k}\Omega}{1\ \text{k}\Omega} = 100$$

The series input capacitor blocks the DC bias so only the pulse content is amplified.

The MCP6022 was selected because:

- its **10 MHz gain-bandwidth product** comfortably exceeds the ~20 kHz bandwidth the 50 µs pulses require;
- its 2.5–5.5 V supply range includes 3.3 V;
- it is power efficient and lightweight.

### High-pass filter

Mains-derived background at 100 Hz sits close enough to the 312 Hz pulse rate to matter, so a high-pass stage removes it.

High-pass filter

$$f_c = \frac{1}{2\pi \times 100\ \text{nF} \times 10\ \text{k}\Omega} = 159\ \text{Hz}$$

High-pass filter magnitude response

---

## 2.3 Implementation and measurement

### Digitising with a comparator

The amplified signal is still analogue and noisy. An **LM393** comparator converts it to clean logic levels, chosen for its **1.3 µs propagation delay** (fast enough for 50 µs pulses), its low cost, and its ability to run from 3.3 V and 0 V rails.

Amplified pulses on the oscilloscope

From the measured amplitude, the threshold was initially set by a 27 kΩ / 1 kΩ divider:

$$V_T = 3.3 \times \frac{1\ \text{k}}{27\ \text{k} + 1\ \text{k}} = 118\ \text{mV}$$

This low threshold meant pulses were still detected when the sensor was not quite touching the rock.

Comparator output

### Two problems, two fixes

Zooming in on a single pulse showed noisy edges caused by high-frequency oscillation:

Noisy pulse edges

**Fix 1 — a low-pass filter** to roll off the high-frequency content:

Low-pass filter

$$f_c = \frac{1}{2\pi \times 3.3\ \text{nF} \times 1\ \text{k}\Omega} = 48\ \text{kHz}$$

48 kHz sits comfortably above the ~20 kHz content of the pulses, so it smooths the edges without swallowing pulses. Combined with the earlier high-pass stage this gives a band-pass response from 159 Hz to 48 kHz:

Band-pass magnitude response

Even so, some noise-triggered pulses survived:

Residual noise triggering the comparator

**Fix 2 — raise the threshold.** Replacing the 27 kΩ resistor with 5.1 kΩ gives:

$$V_T = 3.3 \times \frac{1}{3 + 1} = 825\ \text{mV}$$

This is still below the ~900 mV signal peak, so genuine pulses are detected — at the cost of a shorter detection range. That trade was accepted: the sensor arm places the IR sensor close to the rock anyway.

Smoothed pulse edges after both fixes

### Final circuit

Complete infrared detection circuit

---

## 2.4 Software

The digitised pulse train drives **interrupt pin 2** on the Metro. Every rising edge fires an interrupt that increments a counter, so pulses are caught regardless of what the main loop is doing.

The rate is measured over **five consecutive 200 ms windows**. Each window's count is multiplied by 5 to give a per-second rate, and the five results are averaged. Averaging this way means a single anomalous window — a missed pulse burst, or a spurious trigger — cannot dominate the reading.

Board 2 then classifies the averaged rate as whichever of 312 Hz or 547 Hz it is nearer to, and reports both the raw rate (`IR`), the classification (`IRC`) and a confidence percentage (`IRCO`) derived from how decisively the rate fell on one side of the midpoint.

### Test results

| Test | Expected | Run 1 | Run 2 | Run 3 |
|---|---|---|---|---|
| 1 | 312 Hz | 281 | 328 | 279 |
| 2 | 547 Hz | 530 | 514 | 518 |
| 3 | 547 Hz | 511 | 505 | 499 |
| 4 | 312 Hz | 289 | 310 | 303 |

Every reading falls clearly on the correct side of the ~450 Hz decision boundary, with the worst case (279 Hz against an expected 312 Hz) still more than 170 Hz clear of it. The consistent slight undercount is expected from the Poisson emission statistics over a finite window.

---

## 2.5 Component summary

| Component | Part | Role |
|---|---|---|
| Photodetector | SFH300 | 950 nm phototransistor |
| Amplifier | MCP6022 | Inverting, ×100 |
| Comparator | LM393 | Analogue → logic level |
| High-pass | 100 nF + 10 kΩ | 159 Hz, rejects 100 Hz background |
| Low-pass | 3.3 nF + 1 kΩ | 48 kHz, smooths edges |
| Threshold divider | 5.1 kΩ + 1 kΩ | 825 mV |

---

[← System overview](01-system-overview.md) · [Documentation index](README.md) · [Repo home](../README.md) · [Next: Radio sensing →](03-radio.md)

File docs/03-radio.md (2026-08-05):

[← Infrared sensing](02-infrared.md) · [Documentation index](README.md) · [Repo home](../README.md) · [Next: Ultrasound sensing →](04-ultrasound.md)

# 3. Radio Sensing

**Measures:** rock age
**Output:** age in billions of years, e.g. `#382` → 3.82
**Firmware:** [`sensing/radio/radio_test_code/`](../sensing/radio/radio_test_code/) (test), [`Full_Board_Code/Board 2/`](../Full_Board_Code/Board%202/) (flight)
**Calculations:** [`sensing/radio/COIL_CALCULATIONS.md`](../sensing/radio/COIL_CALCULATIONS.md)

---

## 3.1 The signal

The rock transmits its age on an **89 kHz carrier** using **amplitude-shift keying** — specifically on-off keying, where carrier present means logic `1` and carrier absent means logic `0`. The data is standard **UART framing at 600 baud**: one start bit (logic `0`), eight data bits LSB first, one stop bit (logic `1`).

ASK and UART frame structure

An age is four ASCII characters, the first always `#`. `#123` means 1.23 billion years.

| Bit | 0 | 1 | 2 | 3 | 4 | 5 | 6 | 7 | 8 | 9 |
|---|---|---|---|---|---|---|---|---|---|---|
| Value | 0 (start) | 1 | 1 | 0 | 0 | 0 | 1 | 0 | 0 | 1 (stop) |

### Recovery chain

Getting from a faint magnetic field to a decoded number takes five stages:

```mermaid
flowchart LR
    A["Ferrite coil<br/>antenna"] --> B["Tuned LC<br/>resonant at 89 kHz"]
    B --> C["Non-inverting amp<br/>×101, clips to rails"]
    C --> D["Envelope detector<br/>diode + RC"]
    D --> E["Comparator<br/>Schmitt threshold"]
    E --> F["Metro M0 UART<br/>pin 0, 600 baud"]
    F --> G(["Age value"])
```

Development followed the same order: LTspice simulation first, then a physical circuit, then connection to the Metro M0.

---

## 3.2 Antenna

A **hand-wound ferrite-core coil** was used rather than an air core. Ferrite raises inductance substantially for the same turn count and physical size, concentrating the magnetic field and improving sensitivity to weak signals — and it does so at lower weight than the equivalent air-core coil would need.

Hand-wound ferrite coil

| Parameter | Value |
|---|---|
| Core material | Ferrite |
| Core diameter | 1 cm |
| Core length | 5.5 cm |
| Turns | 120 |
| Wire | 0.40 mm copper |

### Calculated versus measured

Full working is in [`COIL_CALCULATIONS.md`](../sensing/radio/COIL_CALCULATIONS.md). In summary:

Baseline air-core inductance from the solenoid formula, with an end-effect correction $K = 0.859$ for the short coil, gives $L_0^{corrected} = 22.2\ \mu\text{H}$. The ferrite rod's *effective* permeability is far lower than its bulk value because flux leaks at the rod ends:

$$\mu_{eff} = \frac{\mu_{bulk}}{1 + N_d(\mu_{bulk} - 1)} = \frac{125}{1 + 0.044 \times 124} \approx 19.3$$

$$L_{theoretical} = 19.3 \times 22.2 \approx 429\ \mu\text{H}$$

| | Theoretical | Measured | Difference |
|---|---|---|---|
| Inductance | 429 µH | 517 µH | ~85 µH (~17%) |
| Resistance | 0.52 Ω | 0.488 Ω | — |

The ~17% inductance gap is unsurprising given that $\mu_{bulk}$ and $N_d$ were both typical values rather than measured ones. **The measured 517 µH is what the tuning capacitor was sized against**, not the theoretical figure.

### Tuning to resonance

$$f_0 = \frac{1}{2\pi\sqrt{LC}} \implies C = \frac{1}{(2\pi f_0)^2 L}$$

At 89 kHz with $L = 517\ \mu\text{H}$, $C = 6.18\ \text{nF}$. Built from real capacitors in series and parallel this became **6.6 nF**.

Tuned LC circuit in LTspice

LTspice source definitions

`V_carrier` is an 89 kHz sine of 50 mV amplitude; `V_mod` is a 600 Hz square pulse train.

Simulated ASK signal

The simulation shows the expected on-off keyed waveform. On the bench the amplitude was roughly **9× larger** than simulated — measured about 2 cm from the coil and perpendicular to it. Received amplitude varies dramatically with both distance and orientation, which is why the simulation figure should be read as a lower bound rather than a prediction.

Measured ASK signal at the antenna

---

## 3.3 Amplification

The received signal can be as low as a few tens of millivolts. A **non-inverting amplifier with a gain of about 100** was used, deliberately sized so the output clips against the supply rails. The rails are 0 V to 3.3 V, so the negative half of the input is clipped away — which costs nothing, since the following envelope detector discards it anyway.

$$A = \frac{R_2 + R_1}{R_1} = \frac{100\ \text{k} + 1\ \text{k}}{1\ \text{k}} = 101$$

Non-inverting amplifier schematic

### Why not the MCP6002

The **MCP6002** was the obvious first choice — rail-to-rail, 1.8–6 V, and readily available. It was rejected on two grounds:

1. Its **1 MHz gain-bandwidth product** limits usable gain at 89 kHz to roughly ×11, which would have needed several cascaded stages.
2. Its slew-rate-versus-temperature curve showed marginal performance even at 25 °C and 5.5 V, with worse behaviour expected at the 3.3 V the design actually runs at.

| | MCP6002 | MCP6022 |
|---|---|---|
| GBW | 1 MHz | 10 MHz |
| Slew rate | ~0.6 V/µs | 7 V/µs |
| Max gain at 89 kHz | ~11× | ~112× |

MCP6002 slew rate vs temperature
MCP6022 slew rate vs temperature

Bench testing confirmed the prediction, and the **MCP6022** was selected.

### Results

LTspice amplified output

The simulation shows 50 mV amplified to a rail-clipped 0–3 V output with the negative half removed, and the 1.67 ms bit period confirms 600 bits/s.

Measured amplified signal
Base signal against amplified output

On the bench the measured gain was $3.36 / 0.456 = 7.47$ — far below the nominal 101. This is *not* a design failure: the op-amp is saturating against the 3.3 V rail, and the input signal was much larger than 50 mV because the rock sat close to the antenna. The gain figure is meaningless once the output is clipping, which is exactly the intended operating condition.

---

## 3.4 Envelope detection

The amplified output is still a sine wave. The Metro needs the *envelope* of that wave, not the wave itself. A diode, capacitor and resistor do the job: the diode charges the capacitor while the carrier is present, and the resistor discharges it while the carrier is absent.

Envelope detector schematic

Two constraints govern the design:

**The diode drop.** A silicon diode costs about 0.6 V, so the amplifier must drive well above that before the detector sees anything. With ×100 gain this is satisfied even for a 50 mV input.

**The RC cutoff.** The filter must reject the 89 kHz carrier while passing the 600 bit/s data. With $R = 10\ \text{k}\Omega$ and $C = 10\ \text{nF}$:

$$\tau = 100\ \mu\text{s} \implies f_c = 1.59\ \text{kHz}$$

That sits more than an order of magnitude below 89 kHz and above 600 Hz — comfortably inside the window.

LTspice envelope detector output
Envelope detector output against amplified input

The simulation shows the half-wave rectified signal becoming a near-digital envelope, ~0.6 V below the amplified signal as expected from the diode. Zooming in reveals the ripple caused by the capacitor discharging on each negative half-cycle:

Envelope ripple, zoomed

Raising R to 30 kΩ makes the point about time constants concretely — the capacitor no longer fully discharges before the next cycle:

Envelope detector with RC too large

This matters directly for the comparator stage that follows.

Measured envelope detector output
Amplified signal against envelope output

The measured peak-to-peak difference between the two traces is $3.52 - 2.88 = 0.64\ \text{V}$ — the diode drop, as predicted.

---

## 3.5 Comparator / Schmitt trigger

The final analogue stage removes the ripple on each "on" cycle and squares off the capacitor's finite discharge time.

Comparator schematic

This is a non-inverting comparator — the signal enters the `+` terminal — with R4 and R5 dividing $V_{cc}$ to set the threshold, nominally at half supply (~1.65 V).

Threshold selection is the critical trade-off:

- **Too low** and noise alone triggers the output.
- **Too high** and the signal fails to cross it at greater rock-to-antenna distances, where the amplifier output no longer reaches 3.3 V.

LTspice comparator output

The simulated output is a clean digital signal swinging 0 V to 3 V.

Envelope output overlaid with the digital output

Three things are worth noticing in this overlay. The ripple is gone. The output no longer carries the 0.6 V diode drop. And the signal does **not** fall to 0 V when you would naively expect — the traces cross at around 1.6 V, meaning the capacitor must discharge for a finite time before the threshold is reached.

That last point has a real consequence: the comparator alters $T_{on}$ and $T_{off}$, even though their sum still equals the bit period. Both must stay inside the tolerances the Metro's UART peripheral will accept, or framing errors follow.

Measured digital output
Amplified signal against final digital output

The bench measurement backs the simulation up: minimal ripple, and amplitude restored to 3.44 V.

---

## 3.6 Final circuit

Final radio circuit on breadboard

Each stage is visible left to right: antenna tuning capacitors, amplifier, envelope detector, Schmitt trigger. The antenna coil itself sits away from the board for better reception.

> **One non-obvious addition.** A **1 kΩ series resistor** sits between the comparator output and the Metro input pin. Without it, the Metro's internal protection diodes back-drive the comparator output, clamping the signal so it never reaches a full 0–3.3 V swing.

---

## 3.7 Software

The demodulated output feeds the Metro's **hardware UART on pin 0**, which decodes the 600 baud stream autonomously without processor intervention. The firmware:

1. watches the incoming byte stream for the `#` start character;
2. buffers the following three ASCII digits;
3. divides the resulting integer by 100 to give the age in billions of years;
4. **clears the stored age after 5 seconds of silence**, so a value from a previous rock can never be attributed to the next one scanned.

That timeout is small but important — without it the rover would confidently report the last rock's age while parked at an unresponsive one.

---

## 3.8 Reflections

**Inverting versus non-inverting.** Cascading an inverting amplifier with a non-inverting Schmitt trigger (or vice versa) silently inverts the data, which then has to be undone in firmware. Making every stage non-inverting removed that class of bug entirely.

**Threshold in practice.** LTspice assumes a noise-free environment and a constant 50 mV input, neither of which holds on the bench. The threshold was lowered from the simulated half-supply value to about **0.75 V** so the comparator still triggers at greater distances, accepting increased noise susceptibility as the price.

**Antenna orientation.** Induced EMF varies sinusoidally with the angle between transmitting and receiving coils — the signal peaks when the coils are perpendicular and vanishes when they are parallel. Orientation matters as much as proximity, so the antenna angle was tuned during testing and then fixed by the mechanical arm design (see [Mechanical design](06-mechanical-design.md#radio-arm)).

---

[← Infrared sensing](02-infrared.md) · [Documentation index](README.md) · [Repo home](../README.md) · [Next: Ultrasound sensing →](04-ultrasound.md)

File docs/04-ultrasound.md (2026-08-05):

[← Radio sensing](03-radio.md) · [Documentation index](README.md) · [Repo home](../README.md) · [Next: Magnetic field sensing →](05-magnetic-field.md)

# 4. Ultrasound Sensing

**Measures:** rock type, via presence of a 40 kHz tone
**Output:** present / absent
**Firmware:** [`sensing/ultrasonic/ultrasonic_test_code/`](../sensing/ultrasonic/ultrasonic_test_code/) (test), [`Full_Board_Code/Board 2/`](../Full_Board_Code/Board%202/) (flight)
**Design notes:** [`sensing/ultrasonic/Ultrasonic_sensor_notes.md`](../sensing/ultrasonic/Ultrasonic_sensor_notes.md)

---

## 4.1 The signal

Of the four rock types, **Basaltoid and Regolix emit a continuous 40 kHz ultrasonic tone**; Gravion and Lunarite do not. This turns a four-way classification into a binary question.

That framing is what makes the whole subsystem simple. No distance measurement is needed, no amplitude, no phase — only a reliable yes/no that a digital pin can read. Every design decision below follows from taking that constraint seriously rather than building a general-purpose ultrasonic receiver.

---

## 4.2 Transducer

The standard component for the job is a piezoelectric transducer. Two requirements narrowed the field: a centre frequency of exactly 40 kHz, and a *receiver* rather than a transmitter.

The **Prowave 400SR160** met both — the `SR` designation stands for Sound Receiver. Its open-type housing exposes the piezoelectric element directly, giving higher sensitivity than a sealed design at some cost in durability. It was also commonly available in the department labs, avoiding both budget spend and delivery delay.

| Parameter | Value |
|---|---|
| Centre frequency | 40.0 ± 1.0 kHz |
| Receiving sensitivity (0 dB = 1 V/µbar) | −61 dB minimum |
| Capacitance at 1 kHz | 2400 pF ± 20% |
| Bandwidth (−6 dB) | 2.5 kHz |
| Beam angle (−6 dB) | 55° typical |
| Operating temperature | −30 to +70 °C |

The −61 dB sensitivity figure sets the whole design:

$$V_{out} = 10^{-61/20} \times 1\ \text{V/µbar} \approx 0.00089\ \text{V/µbar}$$

Millivolt-level output — amplification is unavoidable.

### Load resistor

The datasheet plots sensitivity against load resistance:

Sensitivity versus loaded resistor

Sensitivity improves markedly from 1 kΩ up to roughly 39–100 kΩ, then plateaus. **39 kΩ** was chosen as the transducer load to ground: near-maximum sensitivity without unnecessarily large component values.

The transducer's narrow 2.5 kHz bandwidth is a bonus here — it rejects acoustic energy at other frequencies before any electronics are involved.

---

## 4.3 Amplifier

A **non-inverting** topology was chosen for its high input impedance, which avoids loading the transducer, and for straightforward gain setting with two resistors.

### Op-amp selection

Three parameters mattered:

- **Supply range** must include 3.3 V, since that is what the Metro's digital pins run at.
- **Rail-to-rail output**, to make full use of the available swing.
- **Gain-bandwidth product**, because usable gain at any frequency is limited by $A_{max}(f) = \text{GBW} / f_{signal}$. At 40 kHz, $A_{max} = \text{GBW} / 40{,}000$.
- **Slew rate.** For a 40 kHz sine of 3 V peak-to-peak, $dV/dt_{max} = 2\pi f A = 2\pi \times 40{,}000 \times 1.5 \approx 0.38\ \text{V/µs}$. A minimum of ~1 V/µs was targeted for margin.

| Op-amp | Slew rate | GBW | Gain at 40 kHz | Verdict |
|---|---|---|---|---|
| LT1366 | 0.25 V/µs | — | ~20× | Too slow |
| MCP6002 | 0.6 V/µs | 1 MHz | ~26× | Used initially |
| MCP6022 | 7 V/µs | 10 MHz | ~250× | **Selected** |

LT1366 gain and phase vs frequency
MCP6022 open-loop gain vs frequency

The MCP6002 was used first. After one was damaged during testing it was replaced with the **pin-compatible MCP6022** — a drop-in swap that brought 10× the bandwidth and far more slew headroom with no circuit changes at all.

### Gain

The amplifier is **deliberately designed to clip** at the supply rail rather than reproduce the signal faithfully. The reasoning is in [§4.5](#45-why-hard-clipping-is-the-right-choice).

To drive the weakest expected signal (~30 mV, at the edge of range where the tone passes through the rock's housing) all the way to the 3.3 V rail:

$$A_{total,min} = \frac{3300\ \text{mV}}{30\ \text{mV}} = 110\times$$

Split across two identical stages that is $\sqrt{110} \approx 10.5\times$ each. A substantially higher gain was chosen so the output still clips reliably at the edge of range:

$$A = 1 + \frac{R_f}{R_1} = 1 + \frac{330\ \text{k}\Omega}{10\ \text{k}\Omega} = 34\times$$

Total gain $34 \times 34 = 1156\times$. The 330 kΩ feedback resistor was picked over 220 kΩ (which would give only 23×) specifically to widen this clipping margin.

The only constraint is bandwidth:

$$f_{-3\text{dB}} = \frac{\text{GBW}}{A} = \frac{10\ \text{MHz}}{34} \approx 294\ \text{kHz}$$

Roughly 7× above the 40 kHz signal, so the extra gain costs nothing at the frequency that matters.

A **100 nF decoupling capacitor** sits across each op-amp supply pin to ground to suppress rail noise.

### Input biasing, deliberately omitted

A textbook single-supply AC amplifier biases the input to mid-rail (~1.65 V) so the output swings symmetrically without the negative half clipping at 0 V. That was left out on purpose: the following stage is a half-wave envelope detector that passes only the positive half-cycle and discards the negative half regardless. Biasing would add components for no functional benefit.

---

## 4.4 Envelope detection

The amplifier output is a large 40 kHz waveform, but a digital pin can extract nothing useful from 40 kHz AC — it needs a steady DC level meaning "present" or "absent".

A **1N4148 diode, 10 kΩ resistor and 100 nF capacitor** do this. The diode passes positive half-cycles to charge the capacitor; the resistor discharges it when the signal disappears.

$$\tau = R \times C = 10\ \text{k}\Omega \times 100\ \text{nF} = 1\ \text{ms} \quad (f_c \approx 159\ \text{Hz})$$

This is **40× longer than one 40 kHz period** (25 µs), so the capacitor barely discharges between cycles and the output is smooth DC. It still settles within about 5 ms — effectively instant at the timescale of a 5-second scan.

Accounting for the ~0.6 V diode drop, the output is roughly **2.6 V when the tone is present** and **~0 V when it is absent**.

---

## 4.5 Why hard clipping is the right choice

High gain saturating the op-amp output would be unacceptable in an audio design. Here it is actively beneficial, for a specific reason:

**The envelope detector charges from the *peak* of the waveform, and a clean sine and a heavily clipped square wave share the same peak voltage.** They therefore produce the same envelope output.

Clipping consequently makes the circuit insensitive to signal strength. Whether the transducer sees 30 mV at the edge of range or 150 mV up close, both saturate to the same rail voltage and yield the same DC level. The detection decision stops depending on distance.

Two components were considered and rejected as a direct result:

- **A precision rectifier**, which would remove the diode drop. Unnecessary — since the output already clips, the 0.6 V drop is a fixed, predictable offset that needs no compensation.
- **A dedicated comparator.** Also unnecessary. The Metro M0's digital input reads anything above ~1.8 V as HIGH and below as LOW. An envelope swinging between ~2.6 V and ~0 V leaves roughly 1 V of margin at each end.

---

## 4.6 Simulation

LTspice circuit

Simulated envelope detector output

The simulation settles to a steady ~2.3 V after a brief startup transient, against ~2.6 V measured on the bench. The 0.3 V difference is immaterial — both sit well above the 1.8 V HIGH threshold.

---

## 4.7 Implementation and results

With the 39 kΩ load in place, the transducer's raw output measured around **150 mV pk-pk** with a 40 kHz signal present at close range. Each stage was verified on the oscilloscope before the next was added:

| Node | Output with 40 kHz signal present |
|---|---|
| Transducer + 39 kΩ load | ~150 mV pk-pk |
| Stage 1 amplifier (×34) | ~3.1 V — clips at supply rail |
| Stage 2 amplifier (×34) | ~3.1 V — fully clipped |
| Envelope detector output | ~2.6 V DC |
| Metro digital input | Logic HIGH |

Final circuit on breadboard

Output with no ultrasound signal
Output with ultrasound signal present

Both captures use 1 V vertical divisions. The absent case reads ~45.6 mV; the present case ~2.63 V.

---

## 4.8 Software

The receiver output is read with `digitalRead()`, since the detection circuitry has already reduced it to a logic level.

To reject transient noise and brief dropouts, a **bidirectional counter** is used: it increments on each HIGH reading up to a ceiling of 5, and decrements on each LOW reading down to 0. Detection is confirmed when the counter reaches 5 and cleared when it returns to 0. A single spurious sample in either direction cannot flip the state.

Samples are taken every **20 ms** using non-blocking `millis()` timing, so ultrasonic monitoring runs concurrently with everything else on Board 2.

---

[← Radio sensing](03-radio.md) · [Documentation index](README.md) · [Repo home](../README.md) · [Next: Magnetic field sensing →](05-magnetic-field.md)

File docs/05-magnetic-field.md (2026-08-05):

[← Ultrasound sensing](04-ultrasound.md) · [Documentation index](README.md) · [Repo home](../README.md) · [Next: Mechanical design →](06-mechanical-design.md)

# 5. Magnetic Field Sensing

**Measures:** rock type, via magnet polarity
**Output:** `UP` / `DOWN` / `UNKNOWN`
**Firmware:** [`sensing/magnetic/Magnetic_test_code/`](../sensing/magnetic/Magnetic_test_code/) (test), [`Full_Board_Code/Board 2/`](../Full_Board_Code/Board%202/) (flight)

---

## 5.1 The problem

Each rock contains a small permanent magnet pointing either up or down, splitting the four types into two pairs:

| Polarity | Rock types |
|---|---|
| **Down** | Basaltoid, Gravion |
| **Up** | Regolix, Lunarite |

What is needed is reliable detection of **field direction** — the sign of the vertical (Z-axis) field — not an accurate measurement of its strength.

The difficulty is geometric. The sensor sits on the rover's arm and must detect the magnet through an air gap and the rock's outer wall, at a distance of **a few centimetres** rather than on contact. This subsystem is the clearest example in the project of a requirement that looks trivial and turns out to drive a complete change of technology.

---

## 5.2 First attempt — AH49E Hall-effect sensor

A linear Hall-effect sensor is the obvious starting point. Its output sits at half the supply voltage with no field applied and swings above or below that midpoint according to field direction — polarity is encoded directly as a voltage, with no processing needed.

AH49E Hall-effect sensor

The **AH49E** was chosen after rejecting two alternatives:

| Part | Why rejected |
|---|---|
| Allegro A1302 | Needs 4.5–6 V, incompatible with the 3.3 V rail; also obsolete |
| Honeywell SS49E | Out of stock and overpriced |
| **AH49E** | **Selected** — runs from 3.3 V, breadboard-friendly TO-92 |

Datasheet sensitivity is 1.6 mV/G at 5 V, scaling to about **1.06 mV/G** on a 3.3 V rail.

### Why it failed

On contact it worked well. Touching the magnet directly onto the sensor face swung the output by roughly **±400 mV**. At the actual 3–4 cm gap between chassis and rock, the change vanished into the noise.

The arithmetic explains why. A magnet's field falls off with the **cube** of distance ($B \propto 1/r^3$), so moving from ~5 mm to ~40 mm is an 8× increase in distance and a **512× drop in field**:

$$\Delta V \approx \frac{400\ \text{mV}}{512} \approx 0.78\ \text{mV}$$

The Metro's 10-bit ADC resolves only $3.3\ \text{V} / 1024 \approx 3.2\ \text{mV}$ per step. A 0.78 mV change is **less than a single ADC count** — invisible, and buried in supply noise besides.
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

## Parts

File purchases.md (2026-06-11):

# Component Orders
**Account:** 1stY RP26/Group15

## Order — 18/05/2026
**Supplier:** OneCall (Farnell and CPC)

| Supplier Ref | Qty | Component | Purpose | Cost |
|---|-----|---|---|---|
| 4472961 | 5 | LM7805 Linear Voltage Regulator, Fixed, 10V In, 5V/1.5A Out, TO-220-3 | Power regulation | £1.28 |
| 3005533 | 2 | LM393AP Analogue Comparator, Differential, 2 Channels, 300ns, 2V to 36V, DIP 8 Pins | Signal comparator stage | £0.32 |
| 3373778 | 2 | AH49EZ3-G1 Hall Effect Sensor, Linear, TO-92S, 3 Pins, 3V to 6.5V | Magnetic sensing | £0.38 |

## Order — 21/05/2026
**Supplier:** OneCall (Farnell and CPC)

| Supplier Ref | Qty | Component | Purpose | Cost |
|---|-----|---|---|---|
| SC21085 | 1 | SEN0419 Fermion Triple Axis Magnetometer Sensor Breakout, BMM150 | Magnetic sensing | £5.55 |
| 1332125 | 2 | MCP6022-E/PC Operational Amplifier, Dual, 2 Channel, 10MHz, 7 V/μs, 2.5V to 5.5V, DIP 8 Pins | Signal amplification | £1.44 |

## Order — 22/05/2026
**Supplier:** OneCall (Farnell and CPC)

| Supplier Ref | Qty | Component | Purpose | Cost |
|---|-----|---|---|---|
| 1332125 | 2 | MCP6022-E/PC Operational Amplifier, Dual, 2 Channel, 10MHz, 7 V/μs, 2.5V to 5.5V, DIP 8 Pins | Signal amplification | £1.44 |

## Order — 29/05/2026
**Supplier:** OneCall (Farnell and CPC)

| Supplier Ref | Qty | Component | Purpose | Cost |
|---|-----|---|---|---|
| 4733267 | 1 | SEN0419 Fermion Triple Axis Magnetometer Sensor Breakout, BMM150 | Magnetic sensing | £5.55 |

## Order — 05/06/2026
**Supplier:** OneCall (Farnell and CPC)

| Supplier Ref | Qty | Component | Purpose | Cost |
|---|-----|---|---|---|
| 3769943 | 1 | SER0047 Servo Motor, Analog Feedback, 6V, 1.47 N·m | Movement | £5.06 |

## Order — 09/06/2026
**Supplier:** EEDStores

| Supplier Ref | Qty | Component | Purpose | Cost |
|---|-----|---|---|---|
| VB0025 | 1 | Stripboard Medium, 95mm × 127mm | Prototyping | £2.04 |

---
**Total: £23.06**

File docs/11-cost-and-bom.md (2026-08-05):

[← Dual-board architecture](10-dual-board-architecture.md) · [Documentation index](README.md) · [Repo home](../README.md) · [Next: References →](12-references.md)

# 11. Cost and Bill of Materials

**Budget:** £60.00
**Spent:** £31.76
**Remaining:** £28.24 (47% of budget unused)
**Account:** 1stY RP26/Group15
**Supplier:** OneCall (Farnell and CPC), plus EEDStores

The full purchase log with supplier references and order dates is in [`purchases.md`](../purchases.md).

---

## 11.1 Components purchased

| Component | Qty | Unit | Line total | Purpose |
|---|---:|---:|---:|---|
| LM7805 linear voltage regulator, TO-220-3 | 5 | £1.28 | £6.40 | Power regulation (contingency — unused) |
| LM393AP dual comparator, DIP-8 | 2 | £0.32 | £0.64 | Comparator stage: radio, infrared |
| AH49EZ3-G1 Hall-effect sensor, TO-92S | 2 | £0.38 | £0.76 | Magnetic sensing (first attempt — abandoned) |
| MCP6022-E/PC dual op-amp, 10 MHz, DIP-8 | 4 | £1.44 | £5.76 | Amplification: radio, infrared, ultrasound |
| SEN0619 triple-axis magnetometer (BMM350) | 2 | £5.55 | £11.10 | Magnetic sensing (final) |
| SER0047 servo motor, 6 V | 1 | £5.06 | £5.06 | Sensor arm rotation |
| Stripboard, 95 × 127 mm | 1 | £2.04 | £2.04 | Prototyping |
| **Total** | | | **£31.76** | |

### Notes on the spend

**Op-amps and comparators were ordered in multiples** so that each subsystem could be prototyped and tested in parallel rather than competing for shared parts. Across four MCP6022 packages (eight channels) the design uses one channel each for radio, infrared and two ultrasound stages, with spares available when one was damaged in testing.

**The LM7805 regulators were never used.** They were ordered as a contingency for power regulation, but the final design runs all circuitry directly from the Metro's regulated 3.3 V rail — which also removed the need for any protection circuitry between the sensor boards and the microcontroller inputs (see [PCB design](08-pcb-design.md#supply-and-output)). At £6.40 they are the largest single piece of unused spend, and the clearest candidate for a cost saving if the project were repeated.

**The AH49E sensors were a dead end**, superseded by the magnetometer once the $1/r^3$ field falloff calculation showed Hall effect could not work at the required distance. £0.76 is a cheap lesson; see [Magnetic field sensing](05-magnetic-field.md#52-first-attempt--ah49e-hall-effect-sensor).

**Two magnetometers were bought** across separate orders (21/05 and 29/05), making the magnetometer the largest line item at £11.10.

---

## 11.2 A note on the conflicting totals

Three different totals for this project appear in the source documents, and they do not agree. Since this documentation is meant to be reliable, the discrepancy is resolved here rather than quietly picking one.

| Source | Figure |
|---|---|
| Project report, § 5.4 prose | £31.76 |
| Project report, § 5.4 BOM table | £23.84 |
| [`purchases.md`](../purchases.md) footer | £23.06 |

**£31.76 is correct.** Multiplying each line in the purchase log by its quantity and summing gives exactly that figure:

```
5 × £1.28  =  £6.40    LM7805
2 × £0.32  =  £0.64    LM393AP
2 × £0.38  =  £0.76    AH49EZ3-G1
2 × £1.44  =  £2.88    MCP6022   (order 21/05)
2 × £1.44  =  £2.88    MCP6022   (order 22/05)
1 × £5.55  =  £5.55    SEN0619   (order 21/05)
1 × £5.55  =  £5.55    SEN0619   (order 29/05)
1 × £5.06  =  £5.06    SER0047
1 × £2.04  =  £2.04    Stripboard
                      ────────
                       £31.76
```

The other two figures are arithmetic slips:

- **£23.06** in `purchases.md` is the sum of the *unit prices* column, without multiplying by quantity.
- **£23.84** in the report's BOM table does not match even that table's own rows (which sum to £28.16), and several of its unit prices differ from the purchase log.

The purchase log's supplier references and order dates are the primary record; the prose figure of £31.76 in the report is the one that agrees with it.

### One further correction

The purchase log lists the magnetometer as **"SEN0419 … BMM150"**. This is a transcription error. The part actually used is the **SEN0619 (Bosch BMM350)** — confirmed by the firmware, which includes `DFRobot_BMM350.h` and instantiates `DFRobot_BMM350_I2C` at address `0x14`:

- [`Full_Board_Code/Board 2/src/main.cpp`](../Full_Board_Code/Board%202/src/main.cpp)
- [`Lonely_Board/platformio.ini`](../Lonely_Board/platformio.ini) — `lib_deps` points at `github.com/DFRobot/DFRobot_BMM350`

The BMM150 and BMM350 are different sensors with different resolutions, so the distinction matters: the 0.1 µT resolution quoted throughout this documentation is the BMM350's.

---

## 11.3 Components not purchased

A significant portion of the build used parts already available in the department labs, which is why the spend came in well under budget:

| Component | Source |
|---|---|
| Adafruit Metro M0 Express × 2 | Provided |
| WINC1500 Wi-Fi shield | Provided |
| SFH300 phototransistor | Lab stock |
| Prowave 400SR160 ultrasonic receiver | Lab stock |
| 1N4148 diodes | Lab stock |
| Ferrite core and 0.40 mm enamelled copper wire | Lab stock |
| Resistors and capacitors | Lab stock |
| DC motors, wheels, H-bridge driver | Provided |
| PLA filament and 3D printing | Department facility |
| PCB manufacture | Department facility |

---

[← Dual-board architecture](10-dual-board-architecture.md) · [Documentation index](README.md) · [Repo home](../README.md) · [Next: References →](12-references.md)

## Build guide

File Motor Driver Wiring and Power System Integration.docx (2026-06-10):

Motor Driver Wiring and Power System Integration

Objective and Aim

The objective of this part of the project is to connect the motor system safely and reliably so that the motors can be powered by the EEEBug battery supply while being controlled by the Metro M0 Express board. To be more specific, the motor wiring shall help the Rover to satisfy three exact aims: Metro M0 Express could control the rover’s motor. What’s more, the motor driver on the EEEBug PCB could run the motor. Additionally, the power supply among the Metro board, the EEEBug PCB, the battery and the motor shall be correct and safe.

System Overview

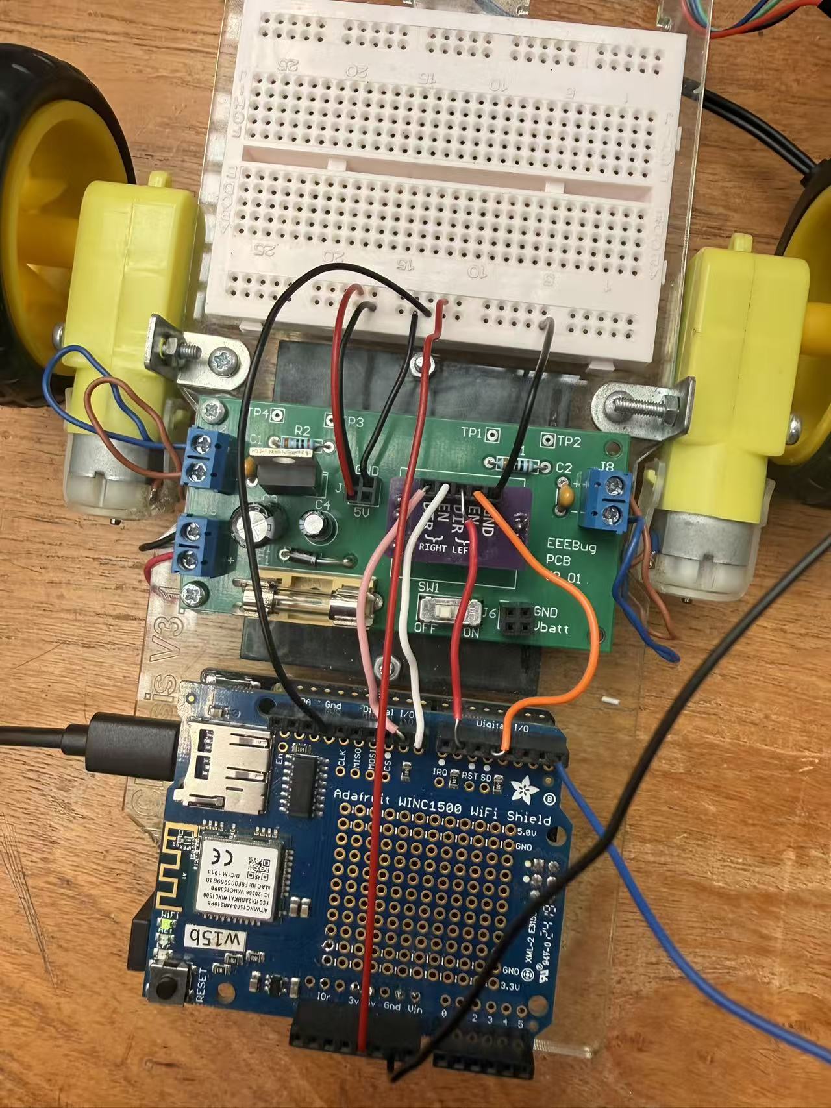
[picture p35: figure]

Fig.1 Actual system

As shown in the figure, for the whole system, the Metro M0 Express is responsible for providing the control signal. The battery is continuously providing power to the motor. The Metro and the EEEBug share the same grounding.

Relevant Hardware

Component | Role in the motor system
Metro M0 Express | Provides 3.3 V logic control signals
EEEBug PCB | Provides power distribution and motor driver interface
Motor driver | Supplies sufficient current to drive the motors
Motors | Provide rover movement
Battery | Powers the motor driver and motor circuit
Jumper wires | Connect Metro board, EEEBug PCB and motors

Table.1 Different components in the motor system

The table clearly shows the roles of each component in the motor system. Since the Metro M0 Express uses 3.3 V logic, all control signals connected to its I/O pins had to remain within the 0–3.3 V range.

Power Connection Design

Battery Connection

There are 4 batteries connected in series to act as the power supply. Each battery is 1.5V, so 4 batteries would provide a total of 6V. The 6V would be connected to the J9 pin to correctly power up the EEEBug PCB.

5V Connection

The 5V connection is used to provide a regulated supply between the Metro board and the EEEBug PCB. The 5V node, rather than Vin or Vbatt, is chosen because Vin and Vbatt may vary depending on the power source. From the design of the EEEBug PCB, the J1 pin would output a 5V, and it is connected to the 5V pin of the Arduino.

Ground Connection

The GND of the metro is directly connected to the GND of the EEEBug. A common ground connection between the Metro board and the EEEBug PCB is essential because the motor driver and the microcontroller need the same voltage reference for the control signals. Otherwise, the control signal would lack a common reference voltage, resulting in an incorrect identification of the HIGH/LOW stage by the motor driver. The real circuit is that the GND pins of the H bridge, J1, as well as the Arduino, are connected together to share the same grounding.

Motor Driver Connection

Role of the motor driver

The motor could not be directly connected to the I/O pins of the Metro M0. The I/O pins are designed for 3.3V signals only. As a result, a motor driver is required to act as a bridge between the high current load and the logic signal.

Motor Output Wiring

The motor terminals will be connected to the motor driver output terminals J7 as well as J8 pins, which will determine the direction of the rotation of the motors. Reversing the connection of the pins would reverse the direction of the rotation of the motors. In other words, the wiring supports forward rotation as well as backward rotation, which would be greatly used in the motion of the rover car.

Arduino Programming

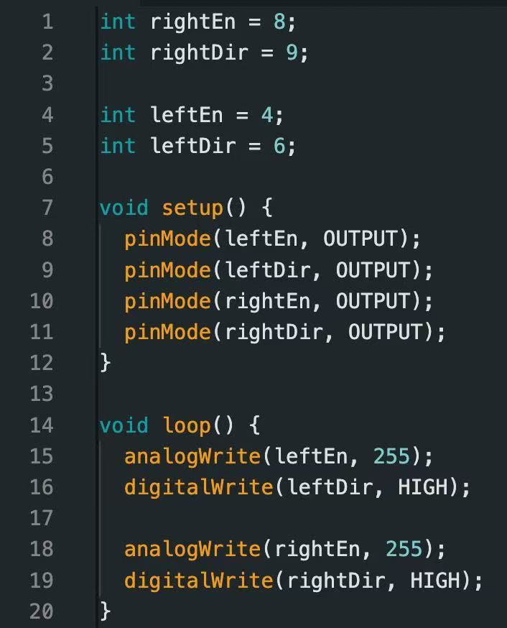
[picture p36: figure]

Fig.2 Arduino Programming relevant to the wiring system

The Arduino Programming defines the behaviours of the pin, as can be seen in Fig.2. As can be seen in the figure, pin 8 is used to activate the right motor. Pin 9 controls the direction of the rotation of the motor. Similarly, pin 4 and pin 6 are used to set up the left motor. The program also sets the velocity of the rotation of the motors.

Control Signal Wiring

The control signal will be sent to the Arduino to correctly control the motion of the rover car. As shown before, the EN pins and the DIR pins, as well, shall be connected to four distinct pins accordingly. The wiring shown in the figures could correctly send the control signal between the motor driver and the Arduino, which enables the control of the motion of the rover car.

Electrical Safety and Constraints

Emphasis shall be put on the voltage connection. There is a warning on the metro board logic level, specifically, 3.3V. If the I/O pin receives a voltage higher than 3.3V, the microcontroller might be damaged. Thus, before powering the circuit, all 5 V and GND connections are checked to avoid reverse polarity or short circuits. Particular care is taken to ensure that no Metro M0 Express I/O pin was exposed to a voltage greater than 3.3 V.

Testing Procedure

Wiring Connection Check

To ensure whether the system works well or not, all wiring shall be checked with care to avoid loose wires or wrong connections before powering up. Loose wires result in an open circuit, whilst wrong connections might cause a short circuit or wrong voltage dissipation, which could pose potential risks towards the electrical components. More precisely, both the 5V connections and the GND connections are checked.

Motor Response Check

There are two useful functions on the motor: enable and direction. First, in order to check the enable function, an enable signal is provided. Observe whether the motors are rotating, and record the direction of the motors. Afterwards, change the direction signal. If the direction reverses, the motor response is working well.

Battery Check

Now directly using the power from the battery instead of an external power source to see if the system still runs properly.

Test results

Test | Expected result | Observed result | Outcome
5V to 5V connection | Metro receives correct supply | Board powered correctly | Pass
GND to GND connection | Shared reference established | Control signals recognised | Pass
Motor enable signal | Motor starts rotating | Motor rotated when enabled | Pass
Motor direction signal | Motor direction changes | Direction changed / did not change | Pass
Battery operation | Motor runs from battery supply | The fuse breaks | Fail

Table.2 Test results of the system

After running separate testing, four tests are passed, and one test is failed.

Problem Encountered

As clearly shown in the table, the battery operation is problematic. The fuse breaks once the switch is turned on. From the other 4 tests, it is known that there is no problem in other parts of the system, but the battery. After checking, the polarity of the battery is incorrectly placed. This suggests that the battery check is not robust enough, and the polarity of the battery placed should also be viewed carefully.

Conclusion

The motor wiring system successfully integrated the Metro M0 Express board with the EEEBug PCB motor driver. The Metro board provided 3.3 V logic control signals, while the motor driver and external power system supplied the current required by the motors. The key design requirements were maintaining a common ground, using the recommended 5 V connection, avoiding voltages above 3.3 V on Metro I/O pins, and verifying the wiring before applying power.

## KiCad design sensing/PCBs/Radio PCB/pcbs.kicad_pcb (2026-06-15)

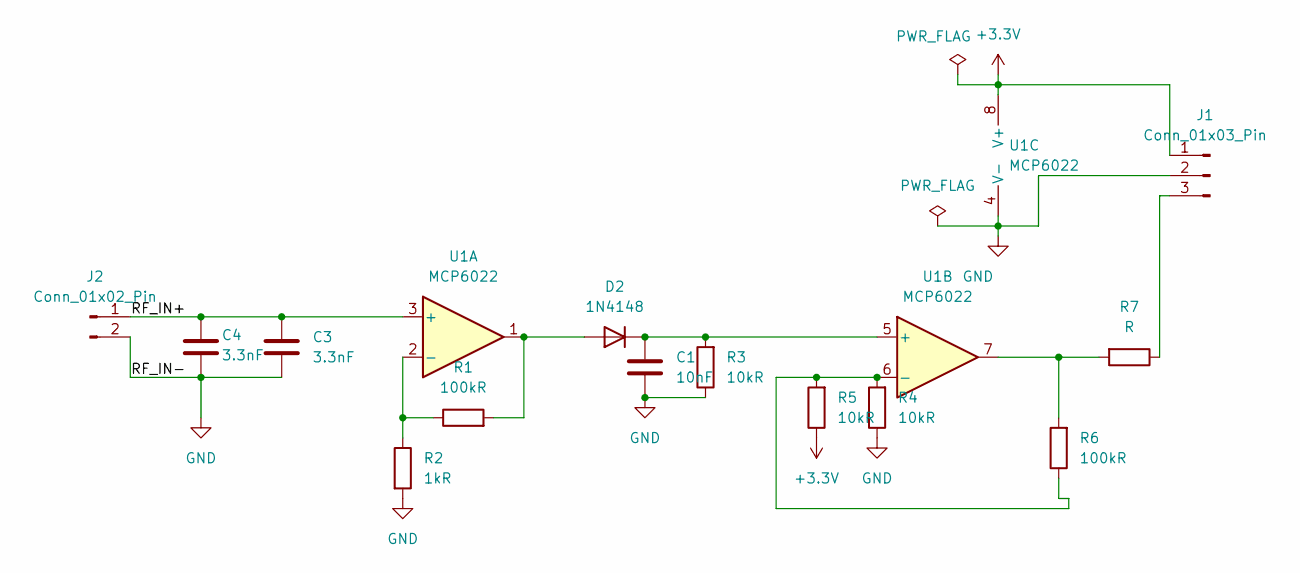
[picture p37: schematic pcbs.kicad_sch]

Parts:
C1: 10nF; C_Disc_D3.4mm_W2.1mm_P2.50mm
C3, C4: 3.3nF; C_Disc_D5.0mm_W2.5mm_P5.00mm
D2: 1N4148; D_DO-35_SOD27_P3.81mm_Vertical_AnodeUp
J1: Conn_01x03_Pin; PinHeader_1x03_P2.54mm_Vertical
J2: Conn_01x02_Pin; PinHeader_1x02_P2.54mm_Vertical
R1, R6: 100kR; R_Axial_DIN0207_L6.3mm_D2.5mm_P7.62mm_Horizontal
R2: 1kR; R_Axial_DIN0207_L6.3mm_D2.5mm_P7.62mm_Horizontal
R3, R4, R5: 10kR; R_Axial_DIN0207_L6.3mm_D2.5mm_P7.62mm_Horizontal
R7: R; R_Axial_DIN0207_L6.3mm_D2.5mm_P7.62mm_Horizontal
U1: MCP6022; DIP-8_W7.62mm

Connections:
+3.3V: J1.1, R5.1, U1.8 (V+)
/RF_IN+: C3.1, C4.1, J2.1, U1.3 (+)
GND: C1.2, C3.2, C4.2, J1.2, J2.2, R2.2, R3.1, R4.1, U1.4 (V-)
unnamed: D2.2 (A), R1.2, U1.1
unnamed: C1.1, D2.1 (K), R3.2, U1.5 (+)
unnamed: J1.3, R7.1
unnamed: R6.2, R7.2, U1.7
unnamed: R1.1, R2.1, U1.2 (-)
unnamed: R4.2, R5.2, R6.1, U1.6 (-)

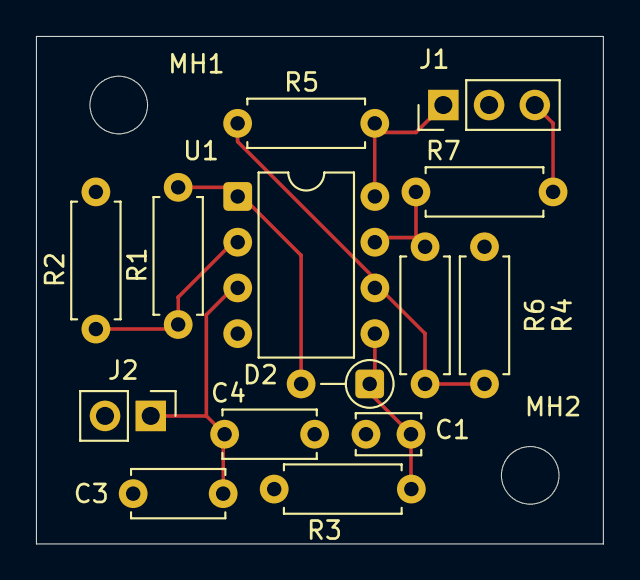
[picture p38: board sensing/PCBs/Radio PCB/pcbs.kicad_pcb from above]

Board: 2 copper layers, 31.5 x 28.2 mm, 16 parts (0 on the bottom side), 9 nets.

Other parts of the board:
MH1, MH2: MountingHole_3.2mm_M3_DIN965

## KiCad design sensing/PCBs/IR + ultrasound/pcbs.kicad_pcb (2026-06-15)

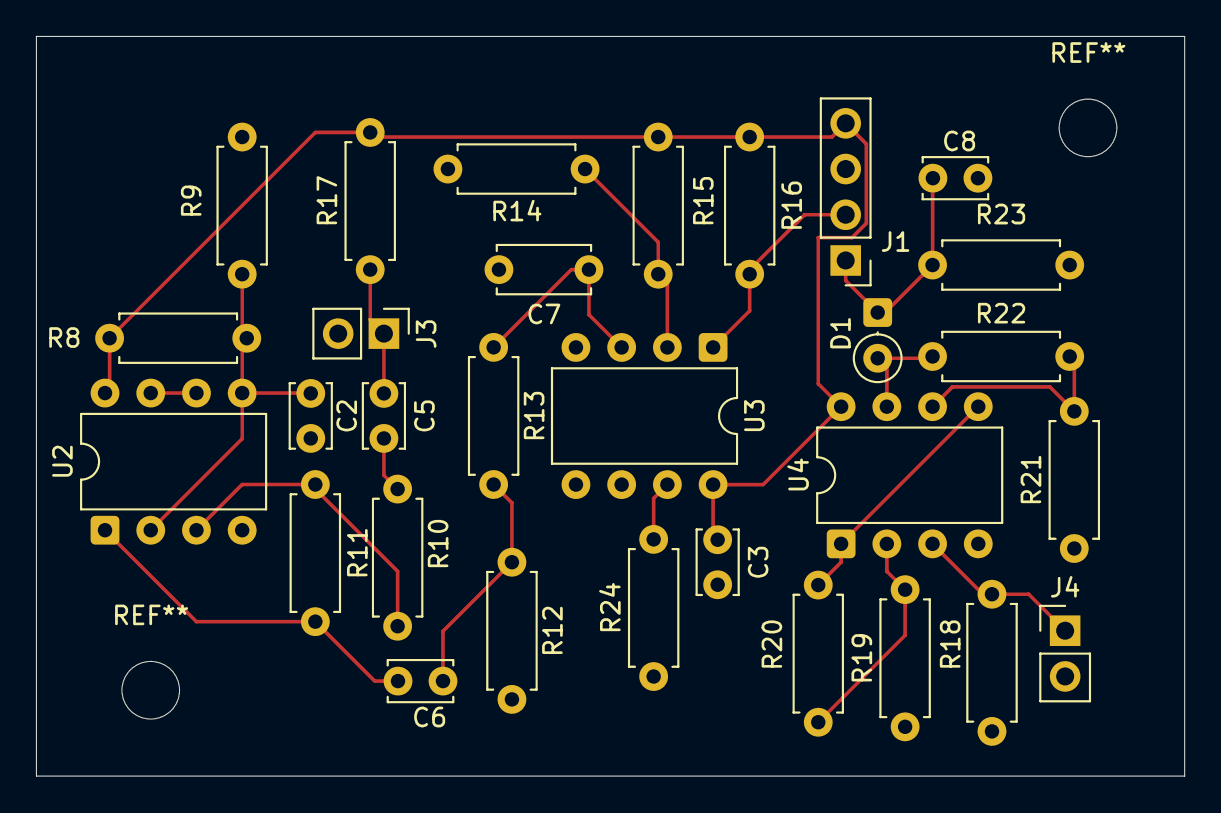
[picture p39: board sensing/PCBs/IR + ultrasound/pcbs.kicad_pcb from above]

Board: 2 copper layers, 63.8 x 41.1 mm, 30 parts (0 on the bottom side), 19 nets.

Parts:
C2, C3, C5, C6, C8: 100nF; C_Disc_D3.4mm_W2.1mm_P2.50mm
C7: 3.3nF; C_Disc_D5.0mm_W2.5mm_P5.00mm
D1: 1N4148; D_DO-35_SOD27_P2.54mm_Vertical_CathodeUp
J1: i/o; PinHeader_1x04_P2.54mm_Vertical
J3: Infra_in; PinHeader_1x02_P2.54mm_Vertical
J4: Ultra_in; PinHeader_1x02_P2.54mm_Vertical
R8, R9, R12, R19, R21, R23, R24: 10kR; R_Axial_DIN0207_L6.3mm_D2.5mm_P7.62mm_Horizontal
R10, R13, R14, R16: 1kR; R_Axial_DIN0207_L6.3mm_D2.5mm_P7.62mm_Horizontal
R11, R17: 100kR; R_Axial_DIN0207_L6.3mm_D2.5mm_P7.62mm_Horizontal
R15: 27kR; R_Axial_DIN0207_L6.3mm_D2.5mm_P7.62mm_Horizontal
R18: 39kR; R_Axial_DIN0207_L6.3mm_D2.5mm_P7.62mm_Horizontal
R20, R22: 330kR; R_Axial_DIN0207_L6.3mm_D2.5mm_P7.62mm_Horizontal
U2, U4: MCP6022; DIP-8_W7.62mm
U3: LM393; DIP-8_W7.62mm

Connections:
+3.3V: C3.1, J1.4, R8.2, R15.1, R16.1, R17.2, U2.8 (V+), U3.8 (V+), U4.8 (V+)
/Vg: C2.1, R8.1, R9.2, U2.2 (-), U2.5 (+)
GND: C2.2, C3.2, C7.2, C8.1, J1.3, J3.2, J4.2, R9.1, R12.1, R14.2, R18.2, R19.1, R21.1, R23.1, R24.1, U2.4 (V-), U3.4 (V-), U3.5 (+), U3.6 (-), U4.4 (V-)
unnamed: C5.2, R10.1
unnamed: C6.1, R11.2, U2.1
unnamed: C6.2, R12.2, R13.1
unnamed: D1.2 (A), R22.1, U4.7
unnamed: C8.2, D1.1 (K), J1.1, R23.2
unnamed: J1.2, R16.2, U3.1
unnamed: C5.1, J3.1, R17.1
unnamed: J4.1, R18.1, U4.3 (+)
unnamed: R24.2, U3.7
unnamed: R10.2, R11.1, U2.3 (+)
unnamed: U2.6 (-), U2.7
unnamed: C7.1, R13.2, U3.3 (+)
unnamed: R14.1, R15.2, U3.2 (-)
unnamed: R19.2, R20.2, U4.2 (-)
unnamed: R20.1, U4.1, U4.5 (+)
unnamed: R21.2, R22.2, U4.6 (-)

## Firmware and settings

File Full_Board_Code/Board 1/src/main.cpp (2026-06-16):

// ═══════════════════════════════════════════════════════════════════════════════
// BOARD 1 — WIFI / MOTOR / WEB SERVER BOARD  (+ SENSOR-ARM SERVO SWEEP)
// Receives sensor CSV from Board 2 via SERCOM1 RX (pin 11) at 9600 baud.
// Hosts the control webpage and drives the motors.
//
// v2.5 CHANGES (this version)
//   - MOTOR DIRECTION FIX. The motor +/GND terminals are wired swapped, so the
//     direction pins were inverted (forward drove backward, left/right swapped).
//     All motor logic now uses DIR_FWD / DIR_REV (DIR_FWD = LOW) instead of raw
//     HIGH/LOW, which corrects both keyboard AND controller paths in one place.
//   - CONTROLLER (GAMEPAD) SUPPORT. A KEYBOARD/CONTROLLER selector plus an Xbox-
//     style gamepad driver (triggers = throttle, right stick X = steer) sending
//     analogue motor speeds to a new /drive?left=&right= endpoint.
//   - SAFETY. Every motor command carries an incrementing sequence number + a
//     per-session id; the firmware discards stale/queued commands. A 500 ms
//     watchdog cuts the motors if no command arrives (WiFi drop / tab close),
//     fed by a ~200 ms client heartbeat on whichever input is active.
//   - (unchanged) candidate-set classifier, per-sensor agreement, scan readings,
//     rock catalog, scrollable event log.
//
// WIRING SUMMARY
// ──────────────────────────────────────────────────────────────────────────────
//  Motor driver LEFT  EN  → Pin 4
//  Motor driver LEFT  DIR → Pin 6
//  Motor driver RIGHT EN  → Pin 8
//  Motor driver RIGHT DIR → Pin 9
//
//  Servo VCC (red)        → 5V   on Metro
//  Servo GND (brown)      → GND  on Metro
//  Servo PWM (orange)     → Pin 3
//
//  Board1 RX ← Board2 TX :  Pin 11 (Board1)  ──── Pin 10 (Board2)
//  GND                   :  GND   (Board1)   ──── GND   (Board2)  ← IMPORTANT
//
//  WiFi Shield plugs on top as normal.
// ═══════════════════════════════════════════════════════════════════════════════

#include <Arduino.h>
#include <Servo.h>
#include "wiring_private.h"

#define USE_WIFI_NINA false
#define USE_WIFI101   true
#include <WiFiWebServer.h>

// ── SERCOM1 UART — RX from Board 2 on pin 11 ─────────────────────────────────
Uart Serial2(&sercom1, 11, 10, SERCOM_RX_PAD_0, UART_TX_PAD_2);

void SERCOM1_Handler() {
  Serial2.IrqHandler();
}

// ── WIFI ──────────────────────────────────────────────────────────────────────
const char ssid[]      = "Shivang iPhone";
const char pass[]      = "heythere";
const int  groupNumber = 15;

// ── INTER-BOARD UART ──────────────────────────────────────────────────────────
const int BOARD_LINK_BAUD = 9600;

// ── MOTOR PINS ────────────────────────────────────────────────────────────────
const int rightEn   = 8;
const int rightDir  = 9;
const int leftEn    = 4;
const int leftDir   = 6;
const int fullSpeed = 255;
const int turnSpeed = 80;

// Motor + and GND terminals are wired swapped, so a direction pin set LOW actually
// drives the wheel FORWARD (HIGH = reverse). All motor logic uses these constants
// instead of raw HIGH/LOW. If you ever rewire the terminals correctly, just swap
// these back to FWD = HIGH, REV = LOW.
const int DIR_FWD = LOW;
const int DIR_REV = HIGH;

// ── DRIVE SAFETY ────────────────────────────────────────────────────────────────
// Watchdog: motors are cut if no drive command arrives within this window. The
// browser re-sends the active command every ~200 ms as a heartbeat, so 500 ms
// gives 2.5x margin. If WiFi drops or the tab closes, the rover stops by itself.
const unsigned long WATCHDOG_MS = 500;
unsigned long lastCmdTime = 0;

// Stale-command filter: every motor command from the browser carries an
// incrementing ?s= sequence number and a ?sid= session id (resets on reload).
// Commands whose sequence isn't newer than the last executed one are discarded,
// so requests that piled up in the TCP queue don't execute out of order.
String lastSid = "";
long   lastSeq = 0;

// ── SERVO (SENSOR ARM) ──────────────────────────────────────────────────────────
const int SERVO_PIN = 3;       // servo signal wire
const int SWEEP_MIN = 70;      // sweep start angle (deg) — tune to your arm
const int SWEEP_MAX = 115;     // sweep end angle   (deg) — tune to your arm
Servo armServo;

// ── SENSOR DATA (populated by Board 2 messages) ───────────────────────────────
String rockAge      = "-.-";
int    irRate       = 0;
int    irClass      = 0;
int    irConfidence = 0;
bool   usDetected   = false;
String magDirection = "UNKNOWN";
String rockType     = "SCANNING";

// ── SCAN STATE ────────────────────────────────────────────────────────────────
bool          scanning  = false;
unsigned long scanStart  = 0;
const unsigned long SCAN_DURATION = 4000;   // sweep length (ms)

// How long (ms) a signal must be seen DURING the sweep to count.
const unsigned long US_MIN_TIME  = 500;     // ultrasound detected this long -> YES
const unsigned long MAG_MIN_TIME = 300;     // a field direction seen this long -> trust it

// Minimum peak confidence (0-100) for an IR class to count as a valid reading.
// The sensor briefly aligns with the emitter during the sweep; we keep the single
// highest-confidence hit for each class and discard everything below this floor.
const int IR_MIN_CONFIDENCE = 20;

// Accumulated time (ms) each signal was present during the sweep
unsigned long usTime       = 0;
unsigned long magUpTime    = 0;
unsigned long magDownTime  = 0;
int           irHighPeak   = 0;   // peak irConfidence seen while irClass == 547
int           irLowPeak    = 0;   // peak irConfidence seen while irClass == 312
unsigned long lastSampleMs = 0;   // used to measure time between loops
int           lastValidIrRate = 0; // IR rate captured at the peak confidence hit

int scanConfidence = 0;
int scanMatches    = 0;   // how many VALID sensors agree with the chosen type
int scanValid      = 0;   // how many sensors produced a usable reading
bool scanDetermined = false; // true if the readings pin down exactly one type

// ── FROZEN SCAN RESULT ─────────────────────────────────────────────────────────
bool   scanHasResult  = false;
bool   scanResUs      = false;     // ultrasound present?
String scanResMag     = "UNKNOWN"; // "UP" / "DOWN" / "UNKNOWN"
String scanResIrState = "NONE";    // "HIGH" / "LOW" / "NONE"
int    scanResIrRate  = 0;         // IR rate (s^-1), 0 if none
String scanResAge     = "-.-";     // radio age at scan time
String agIr  = "-";
String agUs  = "-";
String agMag = "-";

// ── ROCK CLASSIFICATION (candidate-set / intersection model) ───────────────────
// Type bits: BASALTOID=1, GRAVION=2, REGOLIX=4, LUNARITE=8
const int M_BAS = 1 << 0;
const int M_GRA = 1 << 1;
const int M_REG = 1 << 2;
const int M_LUN = 1 << 3;
const int M_ALL = M_BAS | M_GRA | M_REG | M_LUN;
const char* TYPE_NAMES[4] = { "BASALTOID", "GRAVION", "REGOLIX", "LUNARITE" };
// Reference (brief): IR high -> Bas/Lun, IR low -> Gra/Reg
//                    US yes  -> Bas/Reg, US no  -> Gra/Lun
//                    MAG up  -> Reg/Lun, MAG dn -> Bas/Gra

void processScan() {
  armServo.write(SWEEP_MIN);   // return the arm to the start position

  // ── Resolve each sensor to a state ─────────────────────────────────
  bool finalUs = (usTime >= US_MIN_TIME);

  unsigned long magTotal = magUpTime + magDownTime;
  String magState;
  if (magTotal < MAG_MIN_TIME)            magState = "UNKNOWN";
  else magState = (magUpTime >= magDownTime) ? "UP" : "DOWN";

  String irState;
  if (irHighPeak < IR_MIN_CONFIDENCE && irLowPeak < IR_MIN_CONFIDENCE)
    irState = "NONE";
  else
    irState = (irHighPeak >= irLowPeak) ? "HIGH" : "LOW";

  // If we genuinely picked up nothing, bail out
  if (!finalUs && magState == "UNKNOWN" && irState == "NONE") {
    rockType      = "NO DATA";
    scanHasResult = false;
    scanning      = false;
    Serial.println("Scan complete: NO DATA");
    return;
  }

  // ── Candidate masks (each sensor narrows to 2 types) ───────────────
  int irMask  = (irState == "HIGH") ? (M_BAS | M_LUN)
              : (irState == "LOW")  ? (M_GRA | M_REG)
              :                        M_ALL;            // NONE = no constraint
  int usMask  = finalUs ? (M_BAS | M_REG) : (M_GRA | M_LUN); // US always votes
  int magMask = (magState == "UP")   ? (M_REG | M_LUN)
              : (magState == "DOWN") ? (M_BAS | M_GRA)
              :                         M_ALL;           // UNKNOWN = no constraint

  int mask = irMask & usMask & magMask;

  bool conflict = false;
  if (mask == 0) {
    // Sensors contradict. IR+US can never contradict each other, so trust them
    // and let MAG be the one flagged as disagreeing.
    conflict = true;
    mask = irMask & usMask;
    if (mask == 0) mask = usMask;     // last resort (IR was NONE)
  }

  int pc = __builtin_popcount(mask);
  scanDetermined = (pc == 1);

  // Pick the chosen type (lowest set bit)
  int typeIdx = -1;
  for (int i = 0; i < 4; i++) if (mask & (1 << i)) { typeIdx = i; break; }
  int typeBit = (typeIdx >= 0) ? (1 << typeIdx) : 0;
  rockType = (typeIdx >= 0) ? TYPE_NAMES[typeIdx] : "UNKNOWN";

  // ── Per-sensor agreement with the chosen type ──────────────────────
  agIr  = (irState == "NONE")     ? "-" : ((irMask  & typeBit) ? "Y" : "N");
  agUs  = (typeBit)               ? ((usMask & typeBit) ? "Y" : "N") : "-";
  agMag = (magState == "UNKNOWN") ? "-" : ((magMask & typeBit) ? "Y" : "N");

  int agreeCount = 0, validCount = 0;
  if (agIr  != "-") { validCount++; if (agIr  == "Y") agreeCount++; }
  if (agUs  != "-") { validCount++; if (agUs  == "Y") agreeCount++; }
  if (agMag != "-") { validCount++; if (agMag == "Y") agreeCount++; }

  scanMatches = agreeCount;
  scanValid   = validCount;
  if (scanDetermined)
    scanConfidence = (validCount > 0) ? (int)round((float)agreeCount / validCount * 100.0) : 0;
  else
    scanConfidence = (pc > 0) ? (int)round(100.0 / pc) : 0;

  // ── Freeze for the webpage ─────────────────────────────────────────
  scanResUs      = finalUs;
  scanResMag     = magState;
  scanResIrState = irState;
  scanResIrRate  = (irState == "NONE") ? 0 : lastValidIrRate;
  scanResAge     = rockAge;
  scanHasResult  = true;

  scanning = false;
  Serial.println("Scan: " + rockType +
                 " conf=" + String(scanConfidence) + "% agree=" +
                 String(agreeCount) + "/" + String(validCount) +
                 (conflict ? " [CONFLICT]" : "") +
                 (scanDetermined ? "" : " [AMBIGUOUS]"));
  Serial.println("  IR=" + irState + "(" + String(scanResIrRate) + ")" +
                 " US=" + String(finalUs) + " MAG=" + magState +
                 "  ag IR/US/MAG=" + agIr + "/" + agUs + "/" + agMag);
}

// ── PARSE CSV FROM BOARD 2 ────────────────────────────────────────────────────
void parseBoardTwoMessage(String line) {
  line.trim();
  if (line.length() == 0) return;
  int pos = 0;
  while (pos < (int)line.length()) {
    int comma  = line.indexOf(',', pos);
    if (comma < 0) comma = line.length();
    String token = line.substring(pos, comma);
    int colon    = token.indexOf(':');
    if (colon >= 0) {
      String key = token.substring(0, colon);
      String val = token.substring(colon + 1);
      if      (key == "AGE")  rockAge      = val;
      else if (key == "IR")   irRate       = val.toInt();
      else if (key == "IRC")  irClass      = val.toInt();
      else if (key == "IRCO") irConfidence = val.toInt();
      else if (key == "US")   usDetected   = (val == "1");
      else if (key == "MAG")  magDirection = val;
    }
    pos = comma + 1;
  }
}
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
void loop() {
  for (int i = 0; i < 5; i++) server.handleClient();   // serve queued drive commands quickly
  readBoardTwo();

  // Watchdog: if no drive command for WATCHDOG_MS, cut the motors.
  if (millis() - lastCmdTime > WATCHDOG_MS) stopMotors();

  if (scanning) {
    unsigned long now     = millis();
    unsigned long elapsed = now - scanStart;

    if (elapsed >= SCAN_DURATION) {
      processScan();
    } else {
      int angle = SWEEP_MIN + (int)((long)(SWEEP_MAX - SWEEP_MIN) * elapsed / SCAN_DURATION);
      armServo.write(angle);

      unsigned long dt = now - lastSampleMs;
      lastSampleMs = now;

      if (usDetected)                   usTime      += dt;
      if      (magDirection == "UP")    magUpTime   += dt;
      else if (magDirection == "DOWN")  magDownTime += dt;
      if (irClass == 547 && irConfidence > irHighPeak) {
        irHighPeak = irConfidence; lastValidIrRate = irRate;
      } else if (irClass == 312 && irConfidence > irLowPeak) {
        irLowPeak = irConfidence;  lastValidIrRate = irRate;
      }
    }
  }
}

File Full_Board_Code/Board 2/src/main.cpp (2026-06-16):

// ═══════════════════════════════════════════════════════════════════════════════
// BOARD 2 — SENSOR BOARD
// Reads: IR (interrupt), Ultrasonic (digital), Magnetic (BMM350 I2C), Radio (Serial1)
// Sends: CSV sensor data to Board 1 via SERCOM1 TX (pin 10) at 9600 baud
//
// ──────────────────────────────────────────────────────────────────────────────
//  IR sensor output          → Pin 2  (interrupt-capable)
//  Ultrasonic module output  → Pin 3  (digital HIGH = 40kHz detected)
//  BMM350 SDA                → SDA
//  BMM350 SCL                → SCL
//  Radio demodulated output  → Pin 0  (Serial1 RX, 600 baud)
//
//  Board2 TX → Board1 RX :  Pin 10 (Board2)  ──── Pin 11 (Board1)
//  GND                    :  GND   (Board2)  ──── GND    (Board1)  ← IMPORTANT
// ═══════════════════════════════════════════════════════════════════════════════

#include <Arduino.h>
#include <Wire.h>
#include "wiring_private.h"
#include "DFRobot_BMM350.h"

// ── SERCOM1 UART — TX to Board 1 on pin 10 ───────────────────────────────────
Uart Serial2(&sercom1, 11, 10, SERCOM_RX_PAD_0, UART_TX_PAD_2);

void SERCOM1_Handler() {
  Serial2.IrqHandler();
}

// ── BAUD RATES ────────────────────────────────────────────────────────────────
const int RADIO_BAUD      = 600;
const int BOARD_LINK_BAUD = 9600;

// ── RADIO ─────────────────────────────────────────────────────────────────────
String radioBuffer = "";
String rockAge     = "-.-";
unsigned long lastRadioReceived  = 0;
const unsigned long RADIO_TIMEOUT_MS = 5000;

// ── INFRARED ──────────────────────────────────────────────────────────────────
// Kept as close to the working standalone IR code as possible.
// 5 windows of 200ms each = 1s total. Rate = count / 0.2
const int     IR_PIN             = 2;
const int     NUM_AVERAGES       = 5;
const unsigned long MEASURE_WINDOW_MS = 200;
const float   LAMBDA_A           = 547.0;
const float   LAMBDA_B           = 312.0;
const float   CLASSIFY_THRESH    = 419;  // 429.5
const float   IR_NO_ROCK_THRESH  = 50.0;
const unsigned long DEBOUNCE_US  = 40;

volatile unsigned long pulseCount    = 0;
volatile unsigned long lastPulseTime = 0;

void onIRPulse() {
  unsigned long now = micros();
  if (now - lastPulseTime > DEBOUNCE_US) {
    pulseCount++;
    lastPulseTime = now;
  }
}

// IR scan state — non-blocking version of the working loop() logic
int           irSampleIndex  = 0;        // which of the 5 windows we're on
unsigned long irWindowStart  = 0;        // when current window started
float         irTotalRate    = 0.0;      // accumulator for averaging

int           irRate         = 0;        // final averaged rate (s⁻¹)
int           irClass        = 0;        // 0 = no rock, 312, or 547
int           irConfidence   = 0;        // 0–100%

// Called from loop() — non-blocking, updates irRate/irClass/irConfidence
// once per completed 1s cycle (5 x 200ms windows)
void updateIR() {
  unsigned long now = millis();

  // Not time for next window yet
  if (now - irWindowStart < MEASURE_WINDOW_MS) return;

  // --- Window just finished — snapshot and reset counter ---
  noInterrupts();
  unsigned long count = pulseCount;
  pulseCount = 0;
  interrupts();

  float rate = (float)count / (MEASURE_WINDOW_MS / 1000.0);
  irTotalRate += rate;
  irSampleIndex++;
  irWindowStart = now;

  // Not all 5 windows done yet
  if (irSampleIndex < NUM_AVERAGES) return;

  // --- All 5 windows done — classify ---
  float avgRate = irTotalRate / NUM_AVERAGES;
  irRate        = (int)avgRate;

  if (avgRate < IR_NO_ROCK_THRESH) {
    irClass      = 0;
    irConfidence = 0;
  } else {
    float distA          = abs(avgRate - LAMBDA_A);
    float distB          = abs(avgRate - LAMBDA_B);
    float separation     = LAMBDA_A - LAMBDA_B;             // 235
    float distFromThresh = abs(avgRate - CLASSIFY_THRESH);
    float conf           = min(100.0f, (distFromThresh / (separation / 2.0f)) * 100.0f);
    irConfidence         = (int)conf;
    irClass              = (distA <= distB) ? 547 : 312;

    // Print once per 1s cycle — won't flood the monitor
    Serial.print("IR avg=");
    Serial.print(avgRate, 1);
    Serial.print(" class=");
    Serial.print(irClass);
    Serial.print(" conf=");
    Serial.print(irConfidence);
    Serial.println("%");
  }

  // Reset for next cycle
  irTotalRate   = 0.0;
  irSampleIndex = 0;
}

// ── ULTRASONIC ────────────────────────────────────────────────────────────────
const int US_PIN            = 13;
const int US_VOTE_NEEDED    = 5;
const int US_CHECK_INTERVAL = 20;
int           usVoteCount   = 0;
bool          usDetected    = false;
unsigned long lastUsCheck   = 0;

// ── MAGNETIC (BMM350 via I2C) ─────────────────────────────────────────────────
DFRobot_BMM350_I2C bmm350(&Wire, 0x14);
const int     MAG_CHECK_INTERVAL = 200;
String        magDirection       = "UNKNOWN";
unsigned long lastMagCheck       = 0;
bool          magAvailable       = false;

// ── OUTGOING DATA ─────────────────────────────────────────────────────────────
const int     SEND_INTERVAL = 1000;
unsigned long lastSend      = 0;

// ════════════════════════════════════════════════════════════════════════════
// SETUP
// ════════════════════════════════════════════════════════════════════════════
void setup() {
  Serial.begin(115200);
  unsigned long t = millis();
  while (!Serial && millis() - t < 3000);

  Serial1.begin(RADIO_BAUD);

  Serial2.begin(BOARD_LINK_BAUD);
  Serial.println("Radio started");
  
  pinPeripheral(10, PIO_SERCOM);
  pinPeripheral(11, PIO_SERCOM);

  pinMode(IR_PIN, INPUT);
  attachInterrupt(digitalPinToInterrupt(IR_PIN), onIRPulse, FALLING);

  pinMode(US_PIN, INPUT);

  Serial.println("Initialising BMM350...");
  if (bmm350.begin() == 0) {
    bmm350.setOperationMode(eBmm350NormalMode);
    bmm350.setMeasurementXYZ();
    magAvailable = true;
    Serial.println("BMM350 ready.");
  } else {
    Serial.println("BMM350 not found — magnetic sensor disabled, continuing without it.");
  }

  // Start first IR window immediately
  irWindowStart = millis();
  irSampleIndex = 0;
  irTotalRate   = 0.0;
  noInterrupts();
  pulseCount = 0;
  interrupts();

  Serial.println("Board 2 ready.");
}
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

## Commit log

2026-05-13 Add Ultrasonic Sensor Notes documentation
2026-05-13 Add detailed notes on current ultrasonic receiver component and signal requirements
2026-05-14 Add README for Radio Subsystem — Age Detection
    Added detailed documentation for the Radio Subsystem, including signal processing steps, build notes, component research, and testing checklist.
2026-05-18 Add detailed ultrasonic sensor notes including transducer and op-amp requirements, signal flow, and test results
2026-05-18 Add initial project structure for ultrasonic sensor testing, including configuration files, README documentation, and main code implementation
2026-05-19 Add initial implementation for ultrasonic sensor testing, including configuration files, README documentation, and main code
2026-05-29 Add build artifacts and configuration files for Adafruit Metro M0
    - Created new binary files for various FrameworkArduino components including IPAddress, Print, Reset, SERCOM, Stream, Tone, and USB functionalities.
    - Added object files for DFRobot_BMM350 library and its components.
    - Generated firmware binaries (firmware.bin, firmware.elf) for the project.
    - Included idedata.json for IDE integration and project settings.
    - Updated c_cpp_properties.json and launch.json for VSCode debugging support.
    - Added integrity.dat for library dependency tracking.
    - Introduced project.checksum for build integrity verification.
2026-05-31 Add rover website (Board 2 web server) and .gitignore for .pio artifacts
2026-05-31 Changed website code to include sense button and removed hardcoded data
2026-05-31 Added Radio test code Added Radio + Ultrasound + Magnetic test code Added website + RUM code.
2026-06-05 Add initial project structure and configuration for Board 2
    - Created README files for test, include, and lib directories to provide guidance on usage.
    - Added .gitignore to exclude build artifacts and IDE configuration files.
    - Configured VSCode settings and extensions for PlatformIO development.
    - Implemented platformio.ini for Board 2 with dependencies and board configuration.
    - Developed main application logic in src/main.cpp for sensor data handling and communication with Board 1.
    - Updated WiFi credentials in Lonely_Board and rover_website projects for network connectivity.
2026-06-11 Added the IR sensor code to detect pulses
2026-06-13 Add PCB design files for Demo, IR+ultrasound, and Radio boards
    [Demo pcb.kicad_pcb, Demo pcb.kicad_sch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]
2026-06-15 Update motor control and web interface
2026-06-16 Finalised Board code
2026-08-05 docs: professional documentation overhaul
    Replace the one-line README with a full project README and add a
    complete technical documentation set under docs/, derived from the
    group project report.
    - README.md: overview, architecture, classification table, build and
    flashing instructions, operating guide, results summary, team
    - docs/01..12: system overview, the four sensing subsystems, mechanical
    design, movement and control, PCB design, web interface, dual-board
    architecture, cost/BOM, references
    - docs/images/: 71 figures extracted from the report (schematics,
    LTspice simulations, oscilloscope captures, CAD renders, PCB layouts),
    renamed descriptively and re-encoded for the web (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
2026-08-05 docs: rebuild the README around a sensor gallery
    Front page was a wall of text and links. Restructured for scanning.
    Sensor gallery:
    - 2x2 grid with an individual picture per sensor, each linking to
    its chapter: ferrite coil (radio), detection circuit (infrared),
    breadboard receiver (ultrasound), SEN0619 module (magnetic)
    - Sources have wildly different aspect ratios, so each is fitted
    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
2026-08-05 docs: restructure README as a project overview
    Reordered and trimmed so the front page reads as an overview rather
    than a manual.
    Added:
    - "About the project" opening the page with the goals, what the rover
    has to work out about a rock, and the hard constraints (750 g,
    £60, 3.3 V, remote operation) — before any image
    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
